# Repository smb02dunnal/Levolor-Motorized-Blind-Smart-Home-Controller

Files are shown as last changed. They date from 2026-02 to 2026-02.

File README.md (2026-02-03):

# Levolor Motorized Blind Smart Home Controller
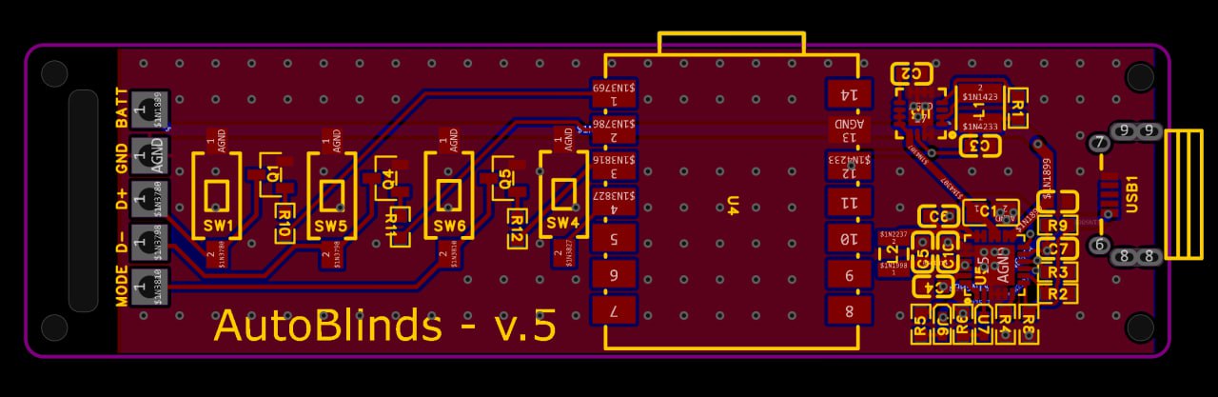
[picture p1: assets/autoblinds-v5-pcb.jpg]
AutoBlinds v.5 PCB


## Who This is For
This solution is **confirmed to work** with **Levolor Motorized Blinds** equipped with the wired-in wand controller that interfaces via Micro-USB.

<p align="center">
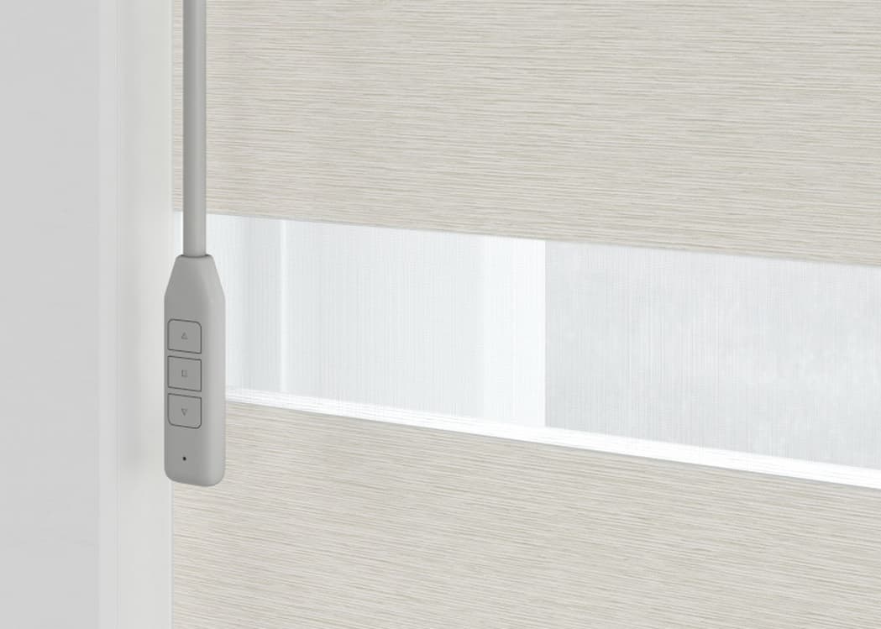
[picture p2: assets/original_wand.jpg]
Original Levolor Wand Controller
  <br/><i>(Original Factory Wand Controller)</i>
</p>

**Broad Applicability:**
While specifically designed for Levolor, this architecture is likely compatible with any motorized blind system that uses a similar wand-based control. If your wand interfaces via a simple pin-shorting logic (even if the connector or pinout differs), this project can be adapted with minor firmware modifications to match your specific wiring.

## Overview
The Levolor Motorized Blind Smart Home Controller is a custom software and hardware solution designed to add smart home capabilities to "dumb" motorized blinds—specifically the **Levolor Wand Motorized Blinds**. 

After realizing the standard wands lacked native smart integration, this project was born to bridge that gap. It uses a custom **ESP32-C3 (Seeed Studio XIAO)** integrated directly into the wand controller, drawing power from the blinds' internal battery.
The wand interfaces via the existing Micro-USB port on the blinds, providing a non-destructive, "plug-and-play" installation.

While designed for blinds, the architecture is a generalized solution for controlling **any low-voltage DC home automation circuit** where power efficiency is critical.

## Features

- **Ultra-Low Power:** Optimized firmware achieving ~100µA idle current to preserve wand battery life.
- **Hardware Agnostic:** Can be adapted for various low-voltage DC applications.
- **Simple HTTP API:** Trigger device actions (Up/Down) via simple GET/POST requests.
- **Arduino Cloud Integration:** Authenticates automatically with `api2.arduino.cc` using client credentials.
- **Home Assistant Ready:** Designed to be exposed as native `cover` entities for high-quality Google Home integration.
- **Remote Logging:** Exposes an endpoint for devices to POST debug logs, which are stored and rotated locally.
- **Auth:** Simple token-based authentication for protecting the bridge.

### System Architecture

```mermaid
graph TD
    User((User)) -->|Voice/App| GoogleHome[Google Home]
    GoogleHome -->|Native Integration| HomeAssistant[Home Assistant]
    HomeAssistant -->|HTTP Request| Bridge[Node.js Bridge]
    Bridge -->|API Call| ArduinoCloud[Arduino IoT Cloud]
    ArduinoCloud -->|MQTT| ESP32[ESP32-C3 in Wand]
    ESP32 -->|GPIO| BlindsMotor[Blinds Motor]
    BlindsMotor -.->|Power| ESP32
```

### Control Logic & Reverse Engineering
Through reverse engineering the original Levolor wand, it was discovered that the motor controller in the blind housing uses a standard Micro-USB interface for more than just charging. The wand communicates by shorting specific pins:

- **D+ / D- / Mode Pins:** Shorting these pins to ground (or each other) triggers the Up, Down, and Set functions.
- **The "Stop" Trick:** There is no dedicated stop pin. Sending a "Stop" command is achieved by shorting the **Up (D+)** and **Down (D-)** pins simultaneously.

### Hardware: Custom Wand Replacement
This project provides a complete **hardware replacement** for the original Levolor Wand housing. The custom-designed 3D-printed enclosure maintains the ergonomic form factor of the original wand while housing the smart internals and drawing power from the blinds' battery pack.
The wand interfaces via the existing Micro-USB port on the blinds, providing a non-destructive, "plug-and-play" installation.

<p align="center">
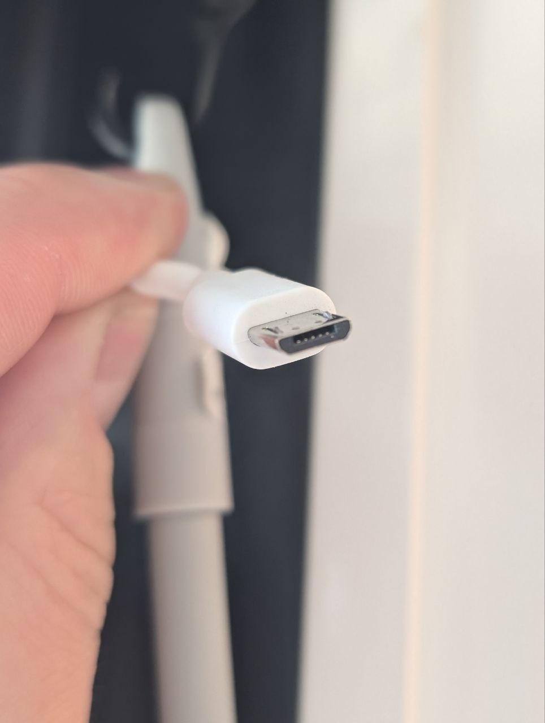
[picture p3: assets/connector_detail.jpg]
Connector Detail
  
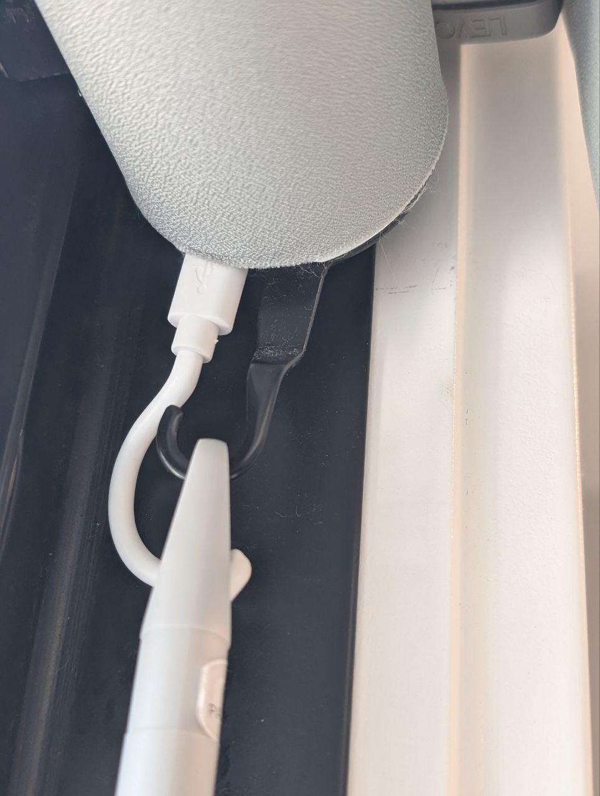
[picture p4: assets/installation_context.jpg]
Installation Context
  
</p>

<p align="center">
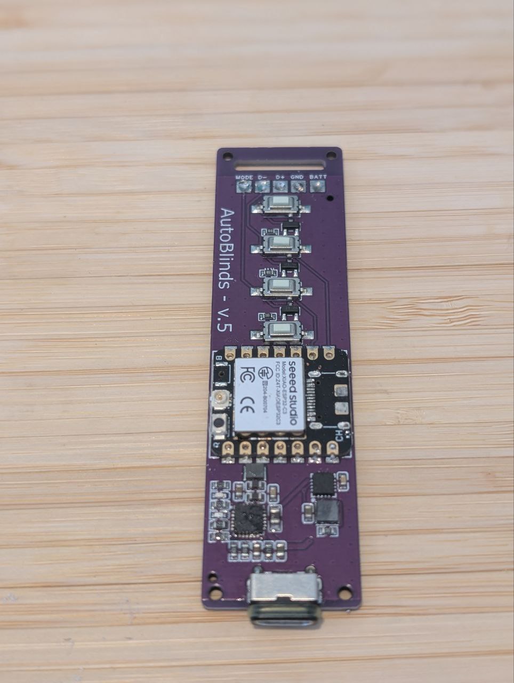
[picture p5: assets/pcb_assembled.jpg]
Assembled PCB
  
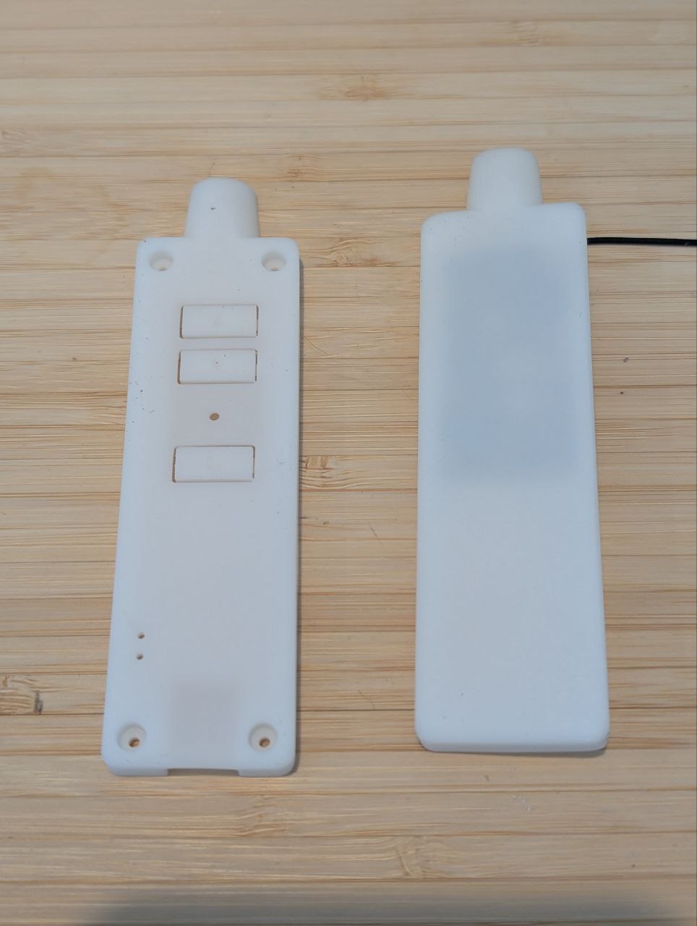
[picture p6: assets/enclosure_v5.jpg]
V5 Enclosure
  
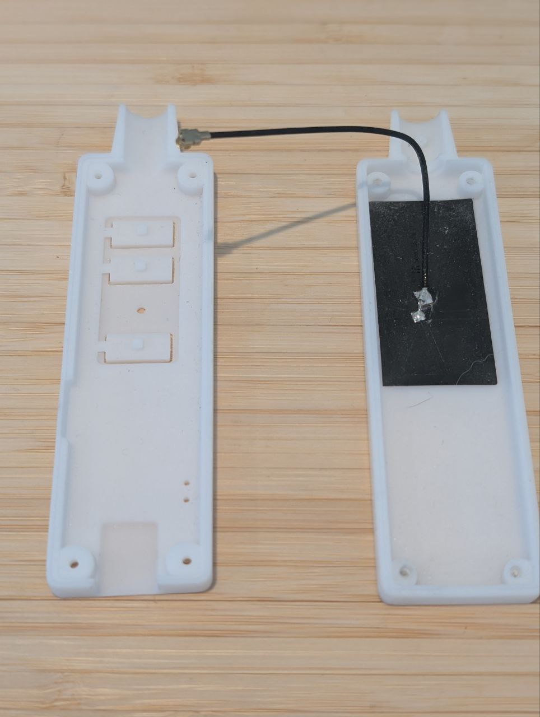
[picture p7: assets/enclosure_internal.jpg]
Internal Enclosure
  
</p>

**Key Technical Details:**
- **Current Draw:** ~100µA idle (optimized via Deep Sleep and power-efficient polling).
- **Circuitry:** Custom PCB using Seeed XIAO ESP32-C3, BQ25886 for battery management, and TPS62152 for efficient power regulation.
- **Versatility:** Although designed for these blinds, the bridge and firmware can control any low-voltage DC circuit.

### Advanced Programming & Calibration
The Levolor motor controller supports several advanced functions (like setting limits or switching modes) via the PROG/SET button and button combinations. These can be triggered through the bridge by sending the appropriate pin shorts.

<p align="center">
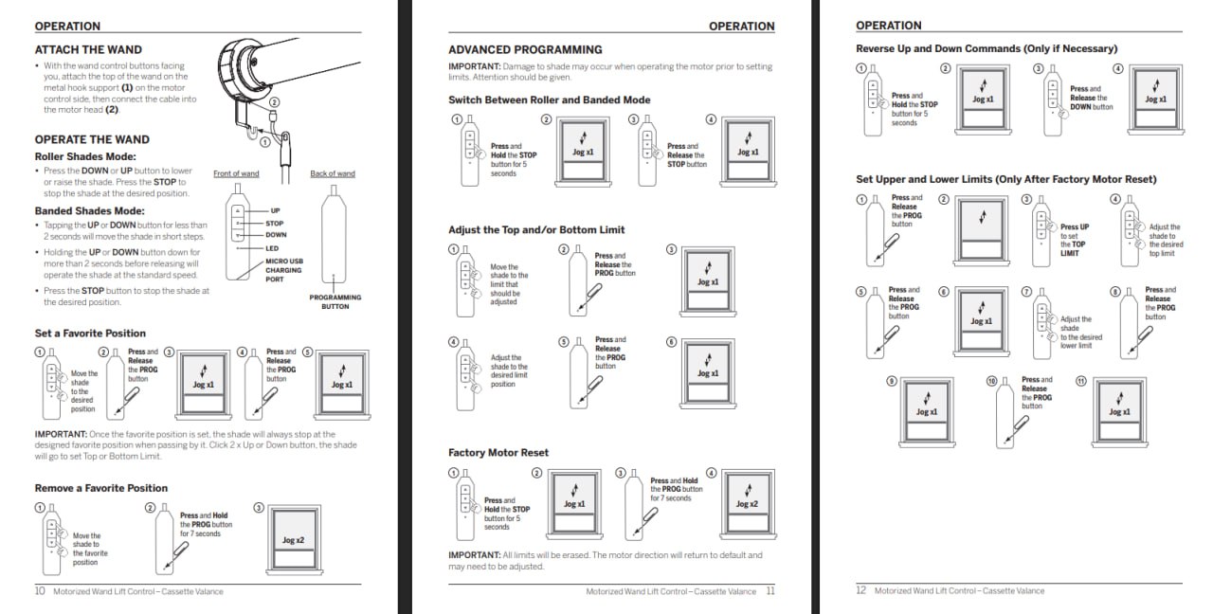
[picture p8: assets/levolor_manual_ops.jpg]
Levolor Manual Operations
  
</p>

## Documentation

| Document | Description |
|---|---|
| [`firmware/README.md`](firmware/README.md) | ESP32 firmware setup, pin mapping, flashing instructions |
| [`hardware/README.md`](hardware/README.md) | PCB design overview, schematics, manufacturing files |
| [`hardware/docs/BOM.md`](hardware/docs/BOM.md) | Bill of Materials with LCSC part numbers |
| [`hardware/case/README.md`](hardware/case/README.md) | 3D printable enclosure files and print settings |
| [`hardware/easyeda/README.md`](hardware/easyeda/README.md) | EasyEDA project files for PCB editing |
| [`home-assistant/README.md`](home-assistant/README.md) | Home Assistant integration for Google Home support |

## Setup

### Prerequisites

- **Node.js** v18 or later
- **npm** v9 or later
- **Arduino IoT Cloud** account with API credentials
- Assembled hardware (see [Hardware Documentation](hardware/README.md))
- ESP32 flashed with firmware (see [Firmware Documentation](firmware/README.md))

### 1. Arduino IoT Cloud Setup

Create a "Thing" in Arduino IoT Cloud with these properties:
- `up` (Boolean, Switch/Push): Triggers the blinds to open
- `down` (Boolean, Switch/Push): Triggers the blinds to close
- `debug_log` (String, Read-Only): Used by the ESP32 to report battery health and diagnostics

Then create an **API Key** under Arduino IoT Cloud → Integrations → API Keys.

### 2. Bridge Installation

```bash
git clone https://github.com/smb02dunnal/Levolor-Motorized-Blind-Smart-Home-Controller.git
cd Levolor-Motorized-Blind-Smart-Home-Controller/server
npm install
```

### 3. Configure Credentials

Create a `.env` file in the `server/` directory:

```env
PORT=8080

# Secure your bridge (recommended)
AUTH_TOKEN=your-secret-local-token

# Arduino IoT Cloud Credentials (from API Keys)
ARDUINO_CLIENT_ID=your-client-id
ARDUINO_CLIENT_SECRET=your-client-secret

# Optional Organization ID
# ARDUINO_ORG=
```

### 4. Map Your Devices

Copy the example config and edit with your Thing/Property IDs:

```bash
cp devices.config.json.example devices.config.json
```

```json
{
  "devices": {
    "office": {
      "thingId": "xxxxxxxx-xxxx-xxxx-xxxx-xxxxxxxxxxxx",
      "deviceId": "xxxxxxxx-xxxx-xxxx-xxxx-xxxxxxxxxxxx",
      "upPropertyId": "xxxxxxxx-xxxx-xxxx-xxxx-xxxxxxxxxxxx",
      "downPropertyId": "xxxxxxxx-xxxx-xxxx-xxxx-xxxxxxxxxxxx"
    }
  }
}
```

### 5. Run the Bridge

```bash
npm start
```

The bridge will start on `http://localhost:8080` (or your configured PORT).

For production, consider using a process manager like **pm2** or running as a **systemd** service.

## Usage

### Control a Device
```bash
# Open office blinds
curl "http://localhost:8080/set/office/up?token=your-secret-local-token"

# Close master bedroom blinds
curl "http://localhost:8080/set/master/down?token=your-secret-local-token"
```

### View Logs
```bash
# View last 200 lines of logs for 'office'
curl "http://localhost:8080/log/office?token=your-secret-local-token"
```

## Hardware

Custom PCB design using Seeed XIAO ESP32-C3 with battery charging (BQ25886) and power management (TPS62152). See the [Hardware Documentation](hardware/README.md) for schematics, Gerber files, and assembly instructions.

## Future Work

- **Further battery optimization** — Continue reducing idle current draw to maximize battery life
- **Smaller PCB form factor** — Shrink the board to fit within the original Levolor wand enclosure, requiring:
  - Double-sided PCB layout
  - Custom ESP32-C3 circuit (bare chip instead of Seeed XIAO module)

## License

ISC

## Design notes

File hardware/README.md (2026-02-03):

# Hardware Documentation

Custom PCB design for the Arduino IoT Blinds Controller — a low-power, battery-operated ESP32 board that controls motorized window blinds via Arduino IoT Cloud.

## Design Overview

```
┌─────────────────────────────────────────────────────────────┐
│                                                             │
│   USB-C ──▶ BQ25886 ──▶ Battery ──▶ TPS62152 ──▶ 3.3V     │
│              (charger)              (buck)                  │
│                                                             │
│   XIAO ESP32-C3 ◀──▶ BSS138 Level Shifters ──▶ Motor       │
│        │                                        Driver      │
│        │                                                    │
│        └──▶ WiFi ──▶ Arduino IoT Cloud                     │
│                                                             │
└─────────────────────────────────────────────────────────────┘
```

## Features

- **Ultra-low power:** Designed for battery operation with efficient power management
- **USB-C charging:** BQ25886 handles Li-Ion/Li-Po battery charging
- **WiFi connectivity:** ESP32-C3 connects to Arduino IoT Cloud
- **Level shifting:** BSS138 MOSFETs for interfacing with 5V motor drivers
- **Compact:** Uses Seeed XIAO module to minimize PCB size
- **Tactile buttons:** 4 switches for manual up/down control

## Directory Structure

```
hardware/
├── README.md           # This file
├── gerber/             # PCB manufacturing files
│   ├── Gerber_*.G*     # Copper, silkscreen, solder mask layers
│   ├── Drill_*.DRL     # Drill files (PTH, NPTH, vias)
│   └── How-to-order-PCB.txt
└── docs/
    └── BOM.md          # Bill of Materials with LCSC part numbers
```

## Manufacturing

### PCB Specs
- **Layers:** 2
- **Thickness:** 1.6mm (standard)
- **Surface finish:** HASL or ENIG
- **Minimum trace:** Check Gerber for specifics

### Ordering PCBs
1. Zip the contents of `/gerber/`
2. Upload to [JLCPCB](https://jlcpcb.com), [PCBWay](https://pcbway.com), or similar
3. Select specs (2-layer, 1.6mm, green solder mask typical)
4. Order! (Usually $2-5 for 5 boards)

### Ordering Components
All parts available from [LCSC](https://lcsc.com). See [BOM.md](docs/BOM.md) for part numbers.

## Assembly Notes

1. **Start with SMD components** — Solder smallest parts first (0402 LEDs, 0603 passives)
2. **ICs next** — BQ25886, TPS62152 (both QFN, need hot air or reflow)
3. **Through-hole last** — Switches, USB connector
4. **XIAO module** — Solder headers or direct-solder the module

### Tools Needed
- Soldering iron with fine tip
- Hot air station (for QFN packages) OR solder paste + reflow
- Flux
- Fine tweezers
- Magnification (loupe or microscope)

## Firmware

See the main project [README](../README.md) for the bridge software. The ESP32 firmware that runs on this board connects to Arduino IoT Cloud — Arduino sketch coming soon in Phase 3.

## License

Hardware designs released under [CERN-OHL-P v2](https://ohwr.org/cern_ohl_p_v2.txt) (Permissive).

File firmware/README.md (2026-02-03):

# ESP32 Firmware

Arduino sketch for the blinds controller. Runs on Seeed XIAO ESP32-C3.

## Features

- **Deep Sleep:** Wakes every 2 minutes to check for cloud commands, then sleeps to save battery
- **WiFi Fast Reconnect:** Caches BSSID/channel in RTC memory for sub-second reconnects
- **OTA Updates:** Supports over-the-air firmware updates via Arduino IoT Cloud
- **Physical Stop Button:** Hardware interrupt on D3 to stop blinds movement
- **Cloud Logging:** Optional HTTP logging to LevolorWand-SmartBridge server

## Pin Mapping

| Pin | Function |
|-----|---|
| D0 | UP signal (also used for STOP pulse) |
| D1 | DOWN signal |
| D2 | SET signal |
| D3 | Stop button input (GPIO5, active LOW) |

## Cloud Properties

| Property | Type | Direction | Description |
|---|---|---|---|
| `cloudUp` | Switch | Read/Write | Trigger UP movement |
| `cloudDown` | Switch | Read/Write | Trigger DOWN movement |

## Setup

1. **Create Arduino IoT Cloud Thing**
   - Add two CloudSwitch properties: `cloudUp` and `cloudDown`
   - Note your Device ID and Secret Key

2. **Configure Secrets**
   Edit `arduino_secrets.h`:
   ```cpp
   #define SECRET_DEVICE_KEY "your-device-key"
   #define SECRET_OPTIONAL_PASS "your-wifi-password"  
   #define SECRET_SSID "your-wifi-ssid"
   ```

3. **Upload**
   - Open in Arduino IDE
   - Select board: `XIAO ESP32C3`
   - Upload!

## Power Management

The firmware is optimized for battery life:

- **CPU:** 80MHz (reduced from 160MHz)
- **WiFi:** MAX_MODEM power save mode
- **Sleep:** Deep sleep for 120s between cloud syncs
- **Wake sources:** Timer (120s) or GPIO (stop button)

Typical current consumption:
- Active (WiFi): ~80-120mA
- Deep sleep: ~10-20µA

## Debug Logging

Uncomment these defines in the main `.ino` to enable:
```cpp
#define ENABLE_LOGGING    // HTTP logging to LevolorWand-SmartBridge
#define ENABLE_SERIAL     // Serial monitor output
```

## Files

| File | Description |
|---|---|
| `Blinds_Controller_v1.ino` | Main sketch |
| `thingProperties.h` | Arduino IoT Cloud configuration (auto-generated) |
| `arduino_secrets.h` | WiFi/device credentials (edit this!) |
| `logger.h` | HTTP logging utility |
| `sketch.json` | Arduino IDE project config |

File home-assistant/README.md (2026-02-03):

# Home Assistant Integration

Integrating the Arduino Bridge with Home Assistant allows you to expose your blinds as native `cover` entities. This is highly recommended for **Google Home/Assistant** users, as it ensures the devices are recognized as "Blinds" or "Shutters" rather than generic switches.

## Template Cover Configuration

Add the following to your Home Assistant `configuration.yaml` (or `covers.yaml`):

```yaml
cover:
  - platform: template
    covers:
      office_blinds:
        device_class: blind
        friendly_name: "Office Blinds"
        open_cover:
          service: shell_command.control_blinds
          data:
            device: "office"
            action: "up"
        close_cover:
          service: shell_command.control_blinds
          data:
            device: "office"
            action: "down"
```

## Shell Command Setup

To trigger the bridge, define the following `shell_command`:

```yaml
shell_command:
  control_blinds: 'curl "http://<bridge-ip>:8080/set/{{ device }}/{{ action }}?token=<your-token>"'
```

### Native Google Home UI
Using the Home Assistant `cover` component ensures Google Home displays the correct controls:

<p align="center">
  Google Home Blinds UI
</p>

## Benefits
- **Native UI:** Provides sliders and appropriate icons in Home Assistant.
- **Voice Control:** Allows commands like "Hey Google, open the office blinds" instead of "turn on."
- **Sync:** Ensures Google Home treats the device with the correct device class for a better user experience.

## Future Exploration
The project is currently at v0.5. While the current solution is fully functional, several areas for potential exploration include:
- **Advanced Power Management:** Further firmware optimizations to reduce the idle current draw below the current 100µA target.
- **Integrated ESP32 Design:** Moving away from the Seeed XIAO development board to a fully custom PCB with an onboard ESP32 module.
- **Footprint Reduction:** The ultimate design goal is to shrink the circuitry enough to fit entirely within the original Levolor wand housing, eliminating the need for a custom 3D-printed enclosure.

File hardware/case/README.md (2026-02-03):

# 3D Printed Enclosure

STL files for the blinds controller enclosure.

## Files

| File | Description | Size |
|---|---|---|
| `enclosure_bottom.stl` | Main body / base | 619 KB |
| `enclosure_top.stl` | Lid / cover | 245 KB |

## Print Settings (Suggested)

| Setting | Value |
|---|---|
| Layer Height | 0.2mm |
| Infill | 15-20% |
| Supports | As needed (check overhangs) |
| Material | PLA or PETG |

## Assembly

1. Print both parts
2. Install PCB in bottom enclosure
3. Connect battery and motor wires
4. Snap or screw on the top lid

## Notes

- Check fit with your specific PCB revision
- May need to adjust for different battery sizes
- Ventilation holes recommended if running for extended periods

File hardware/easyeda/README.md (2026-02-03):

# EasyEDA Project Files

Source files for schematic and PCB layout. Open with [EasyEDA](https://easyeda.com/) (free online EDA tool).

## Contents

| Folder | Description |
|---|---|
| `SHEET/` | Schematic sheets |
| `PCB/` | PCB layout |
| `SYMBOL/` | Component schematic symbols |
| `FOOTPRINT/` | Component PCB footprints |
| `project.json` | Project metadata |

## How to Open

### Option 1: Import to EasyEDA Online
1. Go to [easyeda.com](https://easyeda.com/)
2. Create/login to account
3. File → Import → EasyEDA Pro Project
4. Select this folder or zip it first

### Option 2: EasyEDA Pro Desktop
1. Download [EasyEDA Pro](https://easyeda.com/page/download)
2. File → Open Project
3. Navigate to this folder

## Project Structure

- **Schematic1** — Main circuit schematic
- **PCB1** — 2-layer PCB layout

## Modifying the Design

Feel free to fork and modify! Some ideas:
- Add more GPIO breakout pins
- Adjust battery connector footprint
- Add status LEDs
- Change to different ESP32 module

## Exporting

From EasyEDA you can export:
- **Gerber files** (for PCB manufacturing)
- **BOM** (bill of materials)
- **Pick & Place** (for assembly houses)
- **PDF** (schematic documentation)

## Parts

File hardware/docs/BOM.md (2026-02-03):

# Bill of Materials (BOM)

Complete parts list for the Arduino IoT Blinds Controller PCB.

## Summary
- **MCU:** Seeed XIAO ESP32-C3
- **Power:** USB-C input with BQ25886 battery charger + TPS62152 buck converter
- **Logic Level:** BSS138 MOSFETs for 3.3V ↔ 5V shifting

## Component List

| # | Qty | Designator | Value | Package | Manufacturer | Part Number | LCSC |
|---|-----|---|---|---|---|---|---|
| 1 | 1 | C1 | 47µF | C0805 | TDK | C2012X5R1A476MTJ00E | C76636 |
| 2 | 1 | C2 | 3.3nF | C0603 | Samsung | CL10B332KB8NNNC | C1613 |
| 3 | 1 | C3 | 22µF | C0603 | — | — | — |
| 4 | 2 | C4, C7 | 4.7µF | C0603 | — | — | — |
| 5 | 2 | C5, C10 | 10µF | C0603 | Samsung | CL10A106KP8NNNC | C19702 |
| 6 | 1 | C6 | 47nF | C0603 | Samsung | CL10B473KB8NNNC | C1622 |
| 7 | 1 | C8 | 10µF | C0603 | Samsung | CL10A106KP8NNND | C307458 |
| 8 | 1 | L1 | 2.2µH | 3.0×3.0mm | Murata | LQH3NPN2R2MMEL | C668451 |
| 9 | 1 | L2 | 1.5µH | 2.5×2.0mm | KOHERelec | SPM2512-1R5M | C2761859 |
| 10 | 3 | Q1, Q4, Q5 | BSS138 | SOT-23 | LJ | — | C18195371 |
| 11 | 1 | R1 | 100kΩ | R0603 | — | — | — |
| 12 | 1 | R2 | 330Ω | R0603 | UNI-ROYAL | 0603WAF1001T5E | — |
| 13 | 1 | R3 | 3.9kΩ | R0603 | UNI-ROYAL | 0603WAF3901T5E | C23018 |
| 14 | 1 | R4 | 220kΩ | R0603 | UNI-ROYAL | 0603WAF1503T5E | — |
| 15 | 2 | R5, R6 | 2.2kΩ | R0603 | — | — | — |
| 16 | 2 | R8, R9 | 22kΩ | R0603 | — | — | — |
| 17 | 3 | R10, R11, R12 | 1kΩ | R0603 | — | — | — |
| 18 | 4 | SW1, SW4, SW5, SW6 | Tactile Switch | 6.0×3.3mm | XKB | TS-1101-C-W | C318938 |
| 19 | 1 | U3 | TPS62152RGTR | QFN-16 | Texas Instruments | TPS62152RGTR | C2070611 |
| 20 | 1 | U4 | XIAO ESP32-C3 | Module | Seeed | XIAO ESP32C3 | C19189385 |
| 21 | 1 | U5 | BQ25886RGER | QFN-24 | Texas Instruments | BQ25886RGER | C2765094 |
| 22 | 1 | U6 | Green LED | 0402 | YONGYUTAI | YLED0402G | C20608784 |
| 23 | 1 | U7 | Red LED | 0402 | YONGYUTAI | YLED0402R | C21260817 |
| 24 | 1 | USB1 | Micro-USB | SMD | G-Switch | GT-USB-6008A | C2762988 |

## Key ICs

### BQ25886 — Battery Charger
- 1S Li-Ion/Li-Po battery charger
- I²C programmable
- USB-C compatible input
- Handles charge management, thermal regulation

### TPS62152 — Buck Converter  
- 3.3V output for ESP32
- High efficiency (>90%)
- 1A output capability
- Low quiescent current for battery life

### XIAO ESP32-C3 — Microcontroller
- RISC-V core
- WiFi + BLE
- Ultra low power modes
- Arduino IDE compatible

## Ordering

All components available from [LCSC](https://www.lcsc.com/). Use the LCSC part numbers above for easy ordering.

The PCB can be ordered from JLCPCB, PCBWay, or similar services using the Gerber files in `/hardware/gerber/`.

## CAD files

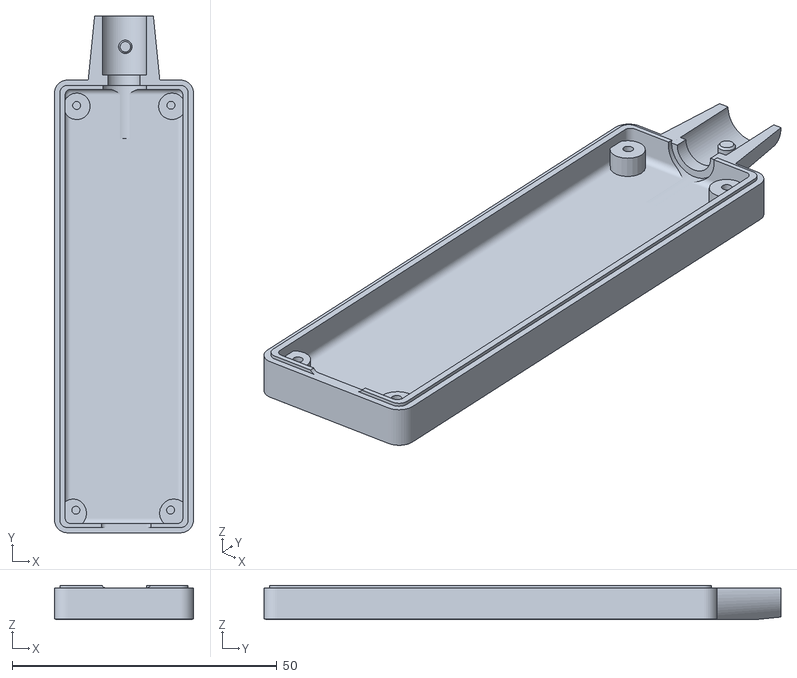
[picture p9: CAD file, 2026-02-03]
hardware/case/enclosure_top.stl
26.2 x 97.5 x 6.50

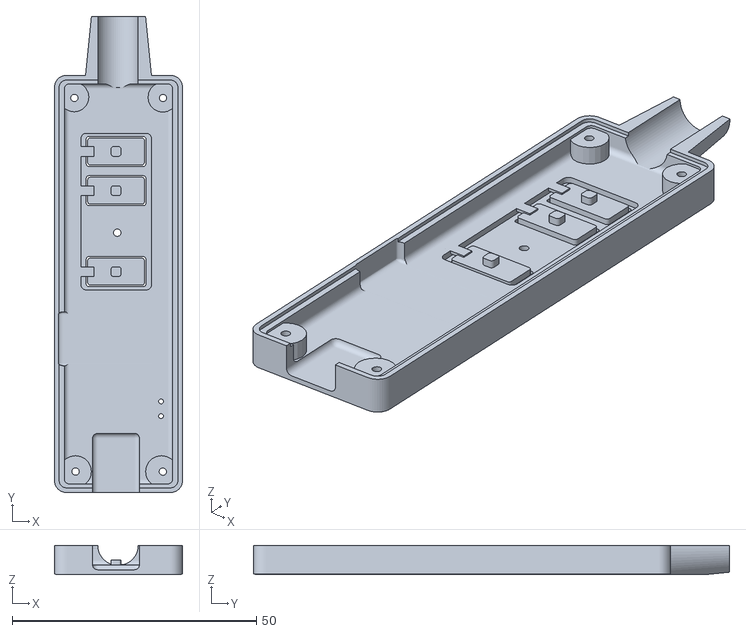
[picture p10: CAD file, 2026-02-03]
hardware/case/enclosure_bottom.stl
26.2 x 97.5 x 6.00

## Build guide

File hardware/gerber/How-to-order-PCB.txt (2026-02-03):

How to Order PCB

Please refer to:
https://prodocs.easyeda.com/en/pcb/order-order-pcb/index.html

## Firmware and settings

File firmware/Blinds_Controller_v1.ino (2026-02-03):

#include "arduino_secrets.h"
#include "thingProperties.h"

#include <esp_err.h>
#include <esp_pm.h>
#include <esp_wifi.h>
#include <esp_wifi_types.h>
#include <esp_sleep.h>

RTC_DATA_ATTR unsigned long g_msSinceStart = 0;

// Enables cloud based logging to our nodejs server
//#define ENABLE_LOGGING

// Enables logging to the serial port for USB connections
//#define ENABLE_SERIAL

#if defined(ENABLE_LOGGING) || defined(ENABLE_SERIAL)
  #include "logger.h"
  #define LOG(data) logMessage(data)
  
  void logMessage(const String &message) {
    unsigned long ms = g_msSinceStart + millis();
    unsigned long seconds = ms / 1000;
    unsigned long minutes = seconds / 60;
    unsigned long hours   = minutes / 60;
  
    seconds %= 60;
    minutes %= 60;
  
    char timeBuf[18];
    snprintf(timeBuf, sizeof(timeBuf), "[%02lu:%02lu:%02lu]", hours, minutes, seconds);
  
  #ifdef SERIAL_LOGGING
    Serial.print(timeBuf);
    Serial.print(message + "\n");
  #endif
  
    logLine(String(timeBuf) + message + "\n");
  }
#else
  #define LOG(data)
#endif
  
#define DELAY(ms) delay(ms);

// Amount of time (s) to sleep for after inactivity
constexpr uint32_t DEEP_SLEEP_LENGTH = 120;

// Wifi connection timeout in seconds
constexpr uint32_t WIFI_CONNECTION_TIMEOUT = 10;

// Define output pins for the blinds control.
constexpr int UP_PIN   = D0;  // Used for "up" and for the "stop" pulse.
constexpr int DOWN_PIN = D1;
constexpr int SET_PIN  = D2;

// Define the input pin (pushbutton) for stop behaviour.
constexpr uint32_t STOP_BUTTON_PIN = D3;
constexpr uint32_t STOP_BUTTON_GPIO = GPIO_NUM_5;

constexpr uint32_t BUTTON_PULSE_MS = 2 * 1000; // 2s

struct WifiConnectionCache{
  uint32_t crc32;   // 4 bytes
  uint8_t channel;  // 1 byte,   5 in total
  uint8_t bssid[6]; // 6 bytes, 11 in total
  uint8_t padding;  // 1 byte,  12 in total
};
RTC_DATA_ATTR volatile WifiConnectionCache g_wifiCache;


bool g_readyToSleep = false;

volatile bool g_stopRequested = false;

bool g_blockForOta = false;
bool g_otaStarted = false;

bool onOTARequestCallback() {
  g_blockForOta = true;
  g_otaStarted = true;
  return true;
}

void deepSleepForSeconds(const uint64_t seconds) {
  LOG("Entering deep sleep for " + String(seconds) + "s\n");
  Serial.flush();

  ArduinoCloud.update();
  DELAY(100);
  
  WiFi.disconnect(true, true);   // drop, erase config from RAM
  esp_wifi_stop();

  // dont leak during sleep
  digitalWrite(UP_PIN, LOW);
  digitalWrite(DOWN_PIN, LOW);
  digitalWrite(SET_PIN, LOW);
  const uint64_t sleepTimeUs = seconds * 1000000ULL;

  g_msSinceStart += millis() + sleepTimeUs / 1000;

  // Wake if the stop button is pressed (interupt)
  esp_deep_sleep_enable_gpio_wakeup(1ULL << STOP_BUTTON_GPIO, ESP_GPIO_WAKEUP_GPIO_LOW);
  
  // Configure timer wakeup
  esp_sleep_enable_timer_wakeup(sleepTimeUs);
  
  // Enter deep sleep
  esp_deep_sleep_start();
}


void IRAM_ATTR handleStopButton() {
  g_stopRequested = true;
}

void connect() {
  initProperties();
  
  // Begin connection to Arduino IoT Cloud.
  ArduinoCloud.begin(ArduinoIoTPreferredConnection);

#ifdef SERIAL_LOGGING
  ArduinoCloud.printDebugInfo();
#endif
  
  ArduinoCloud.addCallback(ArduinoIoTCloudEvent::SYNC, onCloudSync);
  ArduinoCloud.onOTARequestCb(onOTARequestCallback);
}

void onCloudSync(){
  delay(100);
  g_readyToSleep = true;
}

uint32_t calculateCRC32( volatile uint8_t *data, size_t length ) {
  uint32_t crc = 0xffffffff;
  while( length-- ) {
    uint8_t c = *data++;
    for( uint32_t i = 0x80; i > 0; i >>= 1 ) {
      bool bit = crc & 0x80000000;
      if( c & i ) {
        bit = !bit;
      }

      crc <<= 1;
      if( bit ) {
        crc ^= 0x04c11db7;
      }
    }
  }

  return crc;
}

void setup() {  
  // Set the pin modes.
  pinMode(UP_PIN, OUTPUT);
  pinMode(DOWN_PIN, OUTPUT);
  pinMode(SET_PIN, OUTPUT);
  pinMode(STOP_BUTTON_PIN, INPUT_PULLUP);
  digitalWrite(UP_PIN, LOW);
  digitalWrite(DOWN_PIN, LOW);
  digitalWrite(SET_PIN, LOW);
  
  // Dont use Bluetooth
  btStop(); 

  // Enable modem-sleep
  esp_wifi_set_ps(WIFI_PS_MAX_MODEM);

#ifdef SERIAL_LOGGING
  Serial.begin(115200);
#endif

  LOG("Hello World.");
  esp_pm_config_esp32c3_t pm_cfg = {
    .max_freq_mhz = 80,   // you set CPU 80 MHz
    .min_freq_mhz = 80,   // keep fixed or lower if you can
    .light_sleep_enable = true
  };
  esp_pm_configure(&pm_cfg);

  WiFi.persistent(false);
  
  // Try to read WiFi settings from RTC memory
  {
    WifiConnectionCache wifiCache = {};
    memcpy(&wifiCache, (void*)&g_wifiCache, sizeof(wifiCache));
    bool rtcValid = false;
    // Calculate the CRC of what we just read from RTC memory, but skip the first 4 bytes as that's the checksum itself.
    uint32_t crc = calculateCRC32( ((uint8_t*)&wifiCache) + 4, sizeof( wifiCache ) - 4 );
    if( crc == wifiCache.crc32 ) {
      rtcValid = true;
    }
  
    if( rtcValid ) {
      // The RTC data was good, make a quick connection
      WiFi.begin( SSID, PASS, wifiCache.channel, wifiCache.bssid, true );
      LOG("Wifi quick reconnect begin\n");
    }
    else {
      // The RTC data was not valid, so make a regular connection
      WiFi.begin( SSID, PASS );
      LOG("Invalid RTC data for wifi quick connect, just doing a normal connect\n");
    }
  
    int retries = 0;
    while( WiFi.status() != WL_CONNECTED ) {
      retries++;
      if( retries == 10 ) {
        LOG("Wifi quick connect reset\n");
        // Quick connect is not working, reset WiFi and try regular connection
        WiFi.disconnect();
        DELAY(10);
        WiFi.begin( SSID, PASS );
      }
      if( retries == 20 ) {
        LOG("Wifi failure\n");
        return;
      }
      DELAY(WIFI_CONNECTION_TIMEOUT * 1000 / 20);
    }
    
    // Write current connection info back to RTC
    wifiCache.channel = WiFi.channel();
    memcpy( wifiCache.bssid, WiFi.BSSID(), 6 ); // Copy 6 bytes of BSSID (AP's MAC address)
    wifiCache.crc32 = calculateCRC32( ((uint8_t*)&wifiCache) + 4, sizeof( wifiCache ) - 4 );
    memcpy((void*)&g_wifiCache, &wifiCache, sizeof(wifiCache));
  }

  if (esp_sleep_get_wakeup_cause() == ESP_SLEEP_WAKEUP_GPIO) {
    g_stopRequested = true;
  }
  
  // Attach the ISR to the pin, triggering on the falling edge (high→low)
  attachInterrupt(
    digitalPinToInterrupt(STOP_BUTTON_PIN),  // maps D3 → its interrupt number
    handleStopButton,                        // your ISR
    FALLING                                  // when line goes from HIGH to LOW
  );
  
  connect();
}

void loop() { 
  LOG("Start Update");

  // When OTA is available, stay there until it completes.
  // The rest of the loop() does not run and the sketch
  // restarts automatically at the end of the OTA process.
  while (g_blockForOta) {
    ArduinoCloud.update();
    if (g_otaStarted) {
      LOG("Waiting for OTA to finish...");
      g_otaStarted = false;
    }
  }
  
  // Handle cloud connectivity and property updates.
  ArduinoCloud.update();

  // Handle stop case
  if (g_stopRequested) {
    LOG("Stop Requested");
    
    stopMovement();
    g_stopRequested = false;
  }

  if (g_readyToSleep) {
    // Sleep and restart
    deepSleepForSeconds(DEEP_SLEEP_LENGTH);
  }

  vTaskDelay(pdMS_TO_TICKS(10));
}


// --- Command Functions ---

void moveUp() {
  LOG("Moving up...\n");
  digitalWrite(UP_PIN, HIGH);
  DELAY(BUTTON_PULSE_MS);
  digitalWrite(UP_PIN, LOW);
}

void moveDown() {
  LOG("Moving down...\n");
  digitalWrite(DOWN_PIN, HIGH);
  DELAY(BUTTON_PULSE_MS);
  digitalWrite(DOWN_PIN, LOW);
}

// Issues a brief pulse on the UP+DOWN output pin to stop movement.
void stopMovement() {
  LOG("Stopping movement...\n");
  digitalWrite(UP_PIN, HIGH);
  digitalWrite(DOWN_PIN, HIGH);
  DELAY(100);
  digitalWrite(UP_PIN, LOW);
  digitalWrite(DOWN_PIN, LOW);
}


/* Cloud Callbacks */
void onCloudUpChange()   { if (cloudUp)   { cloudUp = false; moveUp();   } }
void onCloudDownChange() { if (cloudDown) { cloudDown = false; moveDown(); } }
